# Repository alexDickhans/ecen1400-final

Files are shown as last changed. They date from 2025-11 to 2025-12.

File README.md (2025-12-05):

# ECEN 1400 Final Project: Interactive Multi-Game Board System

A physical implementation of multiple board games (Gomoku and Connect 4) using Arduino microcontrollers and servo motors, featuring dual input controllers with haptic feedback and game mode selection.

## 📄 [Project Final Report](/final-report.pdf)

## 🎮 Project Overview

This project creates an interactive 5x5 game board system that supports multiple game modes. Players use physical controllers to place X and O pieces represented by servo motor positions. The system includes haptic feedback, game mode selection, and supports two different input methods (button-based and joystick-based controllers).

## 🏗️ System Architecture

The system consists of three main components:

### 1. Main Board Controller (`main-board/`)
- **Hardware**: Arduino Uno with 2x PCA9685 PWM Servo Driver boards
- **Function**: Controls 25 servo motors arranged in a 5x5 grid
- **Features**: 
  - Multiple game modes (Gomoku 3-5 in a row, Connect 4 3-5 in a row)
  - Game mode selection with visual feedback
  - Game logic and win detection
  - Cursor animation and visual feedback
  - Dual controller communication (separate X and O player controllers)
  - Win sequence animations
  - On-board button controls (SELECT and RESET/START)
  - Movement queue system for optimized servo control

### 2. Coarse Input Controller (`coarse/`)
- **Hardware**: Arduino Uno with 5 digital buttons
- **Function**: Provides directional input via discrete buttons (typically used as one player controller)
- **Features**:
  - Up/Down/Left/Right/Select button inputs
  - Dual UART communication (Hardware Serial + SoftwareSerial)
  - Haptic feedback motor control with multiple patterns

### 3. Fine Input Controller (`fine/`)
- **Hardware**: Arduino Uno with analog joystick
- **Function**: Provides directional input via joystick (typically used as the other player controller)
- **Features**:
  - Analog joystick with threshold detection
  - Dual UART communication (Hardware Serial + SoftwareSerial)
  - Haptic feedback motor control with multiple patterns

## 🔌 Pin Configurations

### Main Board Controller
- **PCA9685 Board 1** (Address 0x40, A0 bridged): Controls servos 0-14
- **PCA9685 Board 2** (Address 0x60, all address pins grounded): Controls servos 15-24
- **X Player Controller**: AltSoftSerial on pins 8/9 (RX/TX)
- **O Player Controller**: SoftwareSerial on pins 5/6 (RX/TX)
- **SELECT Button**: Pin 7 (INPUT_PULLUP)
- **RESET/START Button**: Pin 8 (INPUT_PULLUP) - Note: conflicts with AltSoftSerial, consider different pin

### Coarse Controller
- **Buttons**: 
  - Up: Pin 8
  - Down: Pin 9
  - Left: Pin 10
  - Right: Pin 11
  - Select: Pin 12
- **Haptic Motor**: Pin 13
- **UART**: Hardware Serial (0/1) + SoftwareSerial (4/5 - RX/TX)

### Fine Controller
- **Joystick X**: Pin A0
- **Joystick Y**: Pin A1
- **Select Button**: Pin 3 (INPUT_PULLUP)
- **Haptic Motor**: Pin 13
- **UART**: Hardware Serial (0/1) + SoftwareSerial (6/7 - RX/TX)

## 🎯 Game Features

### Game Modes
The system supports 6 different game modes:

**Gomoku Modes (0-2):**
- Mode 0: 3 in a row (tic-tac-toe style, uses 3x3 sub-board)
- Mode 1: 4 in a row
- Mode 2: 5 in a row (classic Gomoku)

**Connect 4 Modes (3-5):**
- Mode 3: Connect 3
- Mode 4: Connect 4 (classic)
- Mode 5: Connect 5

### Servo States
- **STATE_NONE** (Position 300): Empty space
- **STATE_X** (Position 470): Player X piece
- **STATE_O** (Position 100): Player O piece

### Game Mechanics
- **5x5 Grid**: 25 positions for game pieces
- **Variable Win Condition**: 3-5 pieces in a row depending on selected mode
- **Turn-based**: Players alternate turns (X goes first)
- **Visual Cursor**: Animated cursor shows current selection
  - Gomoku: Full 2D movement (up/down/left/right)
  - Connect 4: Horizontal movement only (left/right) in top row, pieces drop to lowest available position
- **Haptic Feedback**: Controllers vibrate on valid/invalid moves and turn changes
- **Game Mode Selection**: Visual pattern on board shows selected mode before game starts

### Animations
- **Cursor Wiggle**: Visual indication of current position (different patterns for empty vs occupied positions)
- **Checkerboard Pattern**: Idle state animation (alternates every 7 seconds)
- **Game Mode Display**: Visual pattern showing selected game mode (diagonal for Gomoku, bottom row for Connect 4)
- **Connect 4 Drop Animation**: Pieces animate falling from top to target position
- **Win Sequence**: Celebration animation when game is won (expanding wave pattern)

## 📡 Communication Protocol

### Input Commands (Controllers → Main Board)
- `u` - Move cursor up (Gomoku only)
- `d` - Move cursor down (Gomoku only)
- `l` - Move cursor left (or decrease game mode in selection)
- `r` - Move cursor right (or increase game mode in selection)
- `s` - Select/place piece (or start game in selection)
- `x` or `o` - Decrease game mode (in game selection mode)

### Feedback Commands (Main Board → Controllers)
- `y` - Valid move (yes)
- `n` - Invalid move (no)
- `t` - Turn notification (your turn)
- `w` - Game won (win pattern)
- `l` - Game lost (lose pattern)

**Note**: Feedback is sent only to the active player's controller (X or O player receives separate communication)

### Haptic Patterns
- **Yes Pattern** (`y`): Three quick short pulses (...)
- **No Pattern** (`n`): Four long pulses (----)
- **Turn Pattern** (`t`): Long-short-long pulses (-.-)
- **Win Pattern** (`w`): Four dots, two dashes (....--)
- **Lose Pattern** (`l`): Four dashes, two dots (----..)

**Timing**:
- Short pulse: 100ms
- Long pulse: 300ms
- Pause between pulses: 150ms

## 🛠️ Setup Instructions

### Hardware Setup
1. **Main Board**:
   - Connect 2x PCA9685 boards to Arduino Uno via I2C (SDA/SCL)
   - Connect 25 servo motors to PWM outputs
   - First PCA9685: Bridge A0 pin for address 0x40, controls servos 0-14
   - Second PCA9685: Ground all address pins for address 0x60, controls servos 15-24
   - Connect SELECT button to pin 7 (with pull-up)
   - Connect RESET/START button to pin 8 (with pull-up) - Note: may conflict with AltSoftSerial
   - Connect X player controller via AltSoftSerial (pins 8/9)
   - Connect O player controller via SoftwareSerial (pins 5/6)

2. **Controllers**:
   - Connect buttons/joystick as per pin configurations
   - Connect haptic motors to pin 13
   - Connect UART communication lines (both Hardware Serial and SoftwareSerial)

### Software Setup
1. Install required Arduino libraries:
   - `Adafruit PWM Servo Driver Library` (for PCA9685 control)
   - `SoftwareSerial` (built-in, for O player controller)
   - `AltSoftSerial` (for X player controller - more reliable than SoftwareSerial)

2. Upload firmware to each Arduino:
   - `main-board.ino` to main controller
   - `coarse.ino` to button controller (assign to one player)
   - `fine.ino` to joystick controller (assign to other player)

## 🎮 How to Play

1. **Enter Game Selection**: Press SELECT button on main board or 's' on either controller
2. **Select Game Mode**: 
   - Use left/right buttons or l/r commands to cycle through modes (0-5)
   - Board displays visual pattern showing selected mode
   - Gomoku modes (0-2): Diagonal pattern showing pieces in a row
   - Connect 4 modes (3-5): Bottom row pattern showing pieces in a row
3. **Start Game**: Press SELECT button again or 's' command to start
4. **Move Cursor**: 
   - Gomoku: Use up/down/left/right to navigate full board
   - Connect 4: Use left/right to select column (cursor stays in top row)
5. **Place Piece**: Press select to place your piece
   - Connect 4: Piece automatically drops to lowest available position in column
6. **Win**: Get required pieces in a row (3-5 depending on mode) to win
7. **Reset**: Press RESET/START button on main board to return to idle, or game automatically resets after win sequence

## 🔧 Technical Details

### Servo Control
- **Frequency**: 50 Hz PWM
- **Pulse Range**: 90-525 (out of 4096)
- **Actual Positions**: 
  - None: 300 (middle-low)
  - X: 470 (middle-high)
  - O: 100 (low)
- **Movement Queue**: Movements are queued and processed with randomization and staggering to prevent power spikes
- **Concurrent Movements**: Maximum 10 servos can move simultaneously
- **Movement Duration**: 300ms per movement

### Debouncing
- **Button Debounce**: 50ms (main board and controllers)
- **Joystick Debounce**: 100ms
- **Joystick Threshold Values**: 
  - Left: < 400
  - Right: > 600
  - Up: < 400
  - Down: > 600
  - Center: 400-600 (both axes)

### Timing
- **Haptic Pulse**: 100ms duration (short), 300ms (long)
- **Pattern Timing**: 100ms short, 300ms long pulses, 150ms pause between
- **Cursor Animation**: 
  - Empty position: 300ms intervals, ±50 amplitude
  - Occupied position: 150ms intervals, ±25 amplitude
- **Checkerboard Pattern**: Changes every 7 seconds
- **Win Sequence**: 200ms per step, 5 seconds total
- **Connect 4 Drop**: ~200-300ms per row during animation

## 🎯 Game Rules

### Gomoku Modes
- Players alternate turns (X goes first)
- Place pieces on empty positions only
- Win by getting the required pieces in a row (3, 4, or 5 depending on mode)
- Rows can be horizontal, vertical, or diagonal
- Mode 0 (3-in-a-row): Uses 3x3 sub-board (indices 1-3)
- Game ends on win or board full (draw)

### Connect 4 Modes
- Players alternate turns (X goes first)
- Pieces drop to the lowest available position in selected column
- Cannot place in full columns
- Win by getting the required pieces in a row (3, 4, or 5 depending on mode)
- Rows can be horizontal, vertical, or diagonal
- Game ends on win or board full (draw)

## 📁 Project Structure

```
ecen1400-final/
├── README.md              # This file
├── main-board/            # Main game controller
│   └── main-board.ino     # Servo control and game logic
├── coarse/                # Button input controller
│   └── coarse.ino         # Digital button handling
└── fine/                  # Joystick input controller
    └── fine.ino           # Analog joystick handling
```

## 🎓 Educational Value

This project demonstrates:
- **Microcontroller Programming**: Arduino C++ programming with state machines
- **Hardware Integration**: Servo control via I2C, multiple PWM driver boards
- **Game Development**: Multiple game modes, win detection algorithms, turn-based logic
- **User Interface Design**: Haptic feedback, visual feedback, game mode selection
- **Communication Protocols**: Dual UART serial communication (Hardware Serial + SoftwareSerial/AltSoftSerial)
- **System Integration**: Multi-device coordination with separate player controllers
- **Resource Management**: Movement queue system, concurrent movement limiting to prevent power issues
- **Animation Systems**: Cursor animations, win sequences, drop animations

## 🔧 Additional Features

### Simulation Mode
The main board code includes a `SIMULATION_MODE` flag (set to 0 by default) that allows testing game logic without servo hardware. When enabled, board state is printed to serial instead of moving servos.

### Debug Commands (Serial Monitor)
- `start` - Enter game selection mode
- `display` - Show current game state
- `reset` - Reset game to idle state

### State Management
- **IDLE**: Shows checkerboard pattern, waiting for game start
- **GAME_SELECT**: Shows selected game mode pattern, allows mode selection
- **ACTIVE**: Game is running, players can make moves

---

**Course**: ECEN 1400 - Introduction to Digital And Analog Electronics  
**Project**: Interactive Multi-Game Board System  
**Technologies**: Arduino, C++, Servo Motors, Haptic Feedback, I2C, UART Communication

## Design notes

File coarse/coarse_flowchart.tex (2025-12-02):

\begin{center}
\begin{tikzpicture}[
    node distance = 0.6cm and 0.6cm,
    auto,
    font=\footnotesize,
    % Styles
    startstop/.style={rectangle, rounded corners, minimum width=2.5cm, minimum height=0.8cm, text centered, draw=black, fill=red!30},
    process/.style={rectangle, minimum width=2.5cm, minimum height=0.8cm, text centered, draw=black, fill=blue!30},
    decision/.style={diamond, minimum width=2cm, minimum height=0.8cm, text centered, draw=black, fill=green!30, inner sep=0pt},
    arrow/.style={thick,->,>=stealth}
]

% Nodes
\node [startstop] (start) {Start};
\node [process, below=of start] (init) {Init Hardware};
\node [startstop, below=of init] (loop) {Main Loop};

\node [process, below=of loop] (check_uart) {Check UART};
\node [decision, below=of check_uart] (has_cmd) {Command?};
\node [process, right=of has_cmd, xshift=0.5cm] (play) {Play Pattern};

\node [process, below=of has_cmd, yshift=-0.5cm] (check_btn) {Process Buttons};
\node [decision, below=of check_btn] (is_pressed) {Pressed?};
\node [process, right=of is_pressed, xshift=0.5cm] (send) {Send Command};

\node [process, below=of is_pressed, yshift=-0.5cm] (haptic) {Handle Haptic};
\node [process, below=of haptic] (delay) {Delay 10ms};

% Arrows
\draw [arrow] (start) -- (init);
\draw [arrow] (init) -- (loop);
\draw [arrow] (loop) -- (check_uart);
\draw [arrow] (check_uart) -- (has_cmd);

% Command branch
\draw [arrow] (has_cmd) -- node[anchor=south] {Yes} (play);
\draw [arrow] (play) |- (check_btn);
\draw [arrow] (has_cmd) -- node[anchor=east] {No} (check_btn);

% Button branch
\draw [arrow] (check_btn) -- (is_pressed);
\draw [arrow] (is_pressed) -- node[anchor=south] {Yes} (send);
\draw [arrow] (send) |- (haptic);
\draw [arrow] (is_pressed) -- node[anchor=east] {No} (haptic);

% Loop back
\draw [arrow] (haptic) -- (delay);
\draw [arrow] (delay) -- ++(0,-0.8) -| ($(loop.west) + (-1cm,0)$) -- (loop.west);

\end{tikzpicture}
\end{center}

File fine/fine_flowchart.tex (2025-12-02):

\begin{center}
\begin{tikzpicture}[
    node distance = 0.6cm and 0.6cm,
    auto,
    font=\footnotesize,
    % Styles
    startstop/.style={rectangle, rounded corners, minimum width=2.5cm, minimum height=0.8cm, text centered, draw=black, fill=red!30},
    process/.style={rectangle, minimum width=2.5cm, minimum height=0.8cm, text centered, draw=black, fill=blue!30},
    decision/.style={diamond, minimum width=2cm, minimum height=0.8cm, text centered, draw=black, fill=green!30, inner sep=0pt},
    arrow/.style={thick,->,>=stealth}
]

% Nodes
\node [startstop] (start) {Start};
\node [process, below=of start] (init) {Init Hardware};
\node [startstop, below=of init] (loop) {Main Loop};

\node [process, below=of loop] (check_uart) {Check UART};
\node [decision, below=of check_uart] (has_cmd) {Command?};
\node [process, right=of has_cmd, xshift=0.5cm] (play) {Play Pattern};

\node [process, below=of has_cmd, yshift=-0.5cm] (check_joy) {Process Joystick};
\node [decision, below=of check_joy] (has_dir) {Direction?};
\node [process, right=of has_dir, xshift=0.5cm] (send) {Send Command};

\node [process, below=of has_dir, yshift=-0.5cm] (haptic) {Handle Haptic};
\node [process, below=of haptic] (delay) {Delay 10ms};

% Arrows
\draw [arrow] (start) -- (init);
\draw [arrow] (init) -- (loop);
\draw [arrow] (loop) -- (check_uart);
\draw [arrow] (check_uart) -- (has_cmd);

% Command branch
\draw [arrow] (has_cmd) -- node[anchor=south] {Yes} (play);
\draw [arrow] (play) |- (check_joy);
\draw [arrow] (has_cmd) -- node[anchor=east] {No} (check_joy);

% Joystick branch
\draw [arrow] (check_joy) -- (has_dir);
\draw [arrow] (has_dir) -- node[anchor=south] {Yes} (send);
\draw [arrow] (send) |- (haptic);
\draw [arrow] (has_dir) -- node[anchor=east] {No} (haptic);

% Loop back
\draw [arrow] (haptic) -- (delay);
\draw [arrow] (delay) -- ++(0,-0.8) -| ($(loop.west) + (-1cm,0)$) -- (loop.west);

\end{tikzpicture}
\end{center}

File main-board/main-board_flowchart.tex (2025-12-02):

\begin{center}
\begin{tikzpicture}[
    node distance = 0.35cm and 0.8cm,
    auto,
    font=\scriptsize,
    % Styles
    startstop/.style={rectangle, rounded corners, minimum width=2cm, minimum height=0.5cm, text centered, draw=black, fill=red!30},
    process/.style={rectangle, minimum width=2cm, minimum height=0.5cm, text centered, draw=black, fill=blue!30},
    decision/.style={diamond, minimum width=1.5cm, minimum height=0.5cm, text centered, draw=black, fill=green!30, inner sep=0pt},
    arrow/.style={thick,->,>=stealth}
]

% Nodes
\node [startstop] (start) {Start};
\node [process, below=of start] (init) {Init};
\node [startstop, below=of init] (loop) {Loop};
\node [process, below=of loop] (queue) {Process Queue};
\node [decision, below=of queue] (state) {State?};

% Side states
\node [process, left=of state, xshift=-2.5cm] (idle) {IDLE};
\node [process, right=of state, xshift=3.5cm] (select) {SELECT};

% Active state flow
\node [decision, below=of state, yshift=-0.2cm] (win) {Win Seq?};
\node [process, right=of win, xshift=1.0cm] (update) {Update Win};

\node [process, below=of win, yshift=-0.2cm] (check) {Check Wins};
\node [process, below=of check] (input) {Proc Input};
\node [decision, below=of input] (valid) {Valid?};

\node [process, below=of valid, yshift=-0.2cm] (move) {Make Move};
\node [process, below=of move] (check2) {Check Win};
\node [decision, below=of check2] (over) {Game Over?};

\node [process, right=of over, xshift=2.5cm] (switch) {Switch};
\node [process, left=of over, xshift=-1.0cm] (cont) {Continue};

\node [process, below=of over, yshift=-0.5cm] (delay) {Delay};

% Arrows
\draw [arrow] (start) -- (init);
\draw [arrow] (init) -- (loop);
\draw [arrow] (loop) -- (queue);
\draw [arrow] (queue) -- (state);

% State branches
\draw [arrow] (state) -- node[above] {IDLE} (idle);
\draw [arrow] (state) -- node[above] {SELECT} (select);
\draw [arrow] (state) -- node[right] {ACTIVE} (win);

% Active flow
\draw [arrow] (win) -- node[above] {Yes} (update);
\draw [arrow] (win) -- node[right] {No} (check);

\draw [arrow] (check) -- (input);
\draw [arrow] (input) -- (valid);

\draw [arrow] (valid) -- node[right] {Yes} (move);
% Valid No -> Delay (route left, wide)
\draw [arrow] (valid) -| ($(valid.west) + (-1.5cm,0)$) |- ($(delay.west) + (0,0.2cm)$);

\draw [arrow] (move) -- (check2);
\draw [arrow] (check2) -- (over);

\draw [arrow] (over) -- node[above] {No} (switch);
\draw [arrow] (over) -- node[above] {Yes} (cont);

% Merging to Delay
\draw [arrow] (idle) |- ($(delay.west) + (-0.5cm,0)$);
\draw [arrow] (select) |- ($(delay.east) + (0.5cm,0)$);

% Update Win -> Delay
\draw [arrow] (update) |- ($(delay.east) + (0.2cm,0.2cm)$);

% Switch -> Delay
\draw [arrow] (switch) |- (delay);

% Continue -> Delay
\draw [arrow] (cont) |- (delay);

% Loop back
\draw [arrow] (delay) -- ++(0,-0.5) -| ($(loop.west) + (-5.5cm,0)$) -- (loop.west);

\end{tikzpicture}
\end{center}

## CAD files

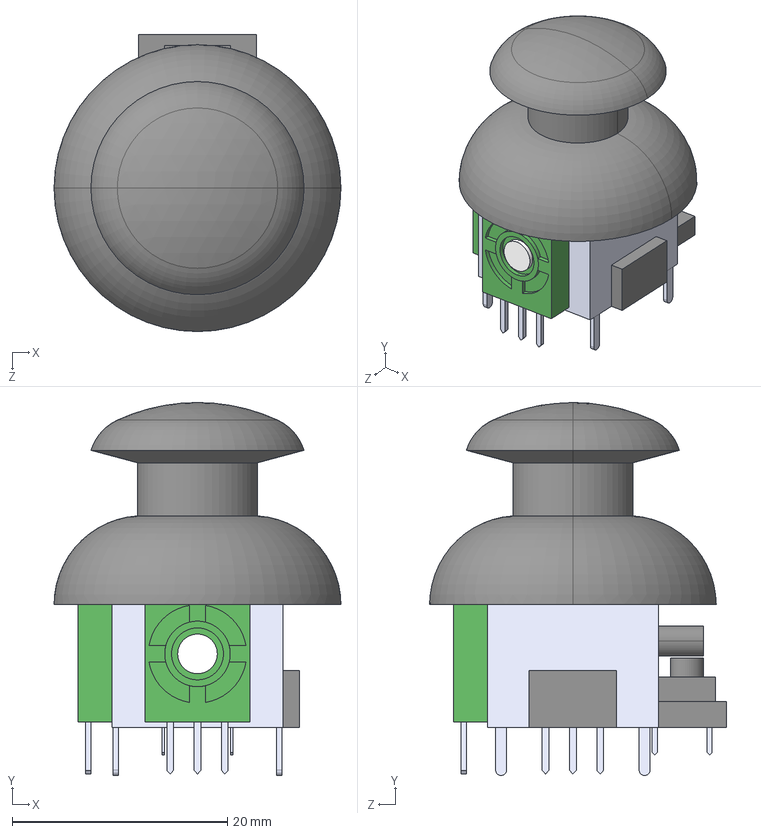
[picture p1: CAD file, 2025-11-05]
final_schematics/COM_09032/COM-09032.step
26.7 x 34.7 x 27.6 mm

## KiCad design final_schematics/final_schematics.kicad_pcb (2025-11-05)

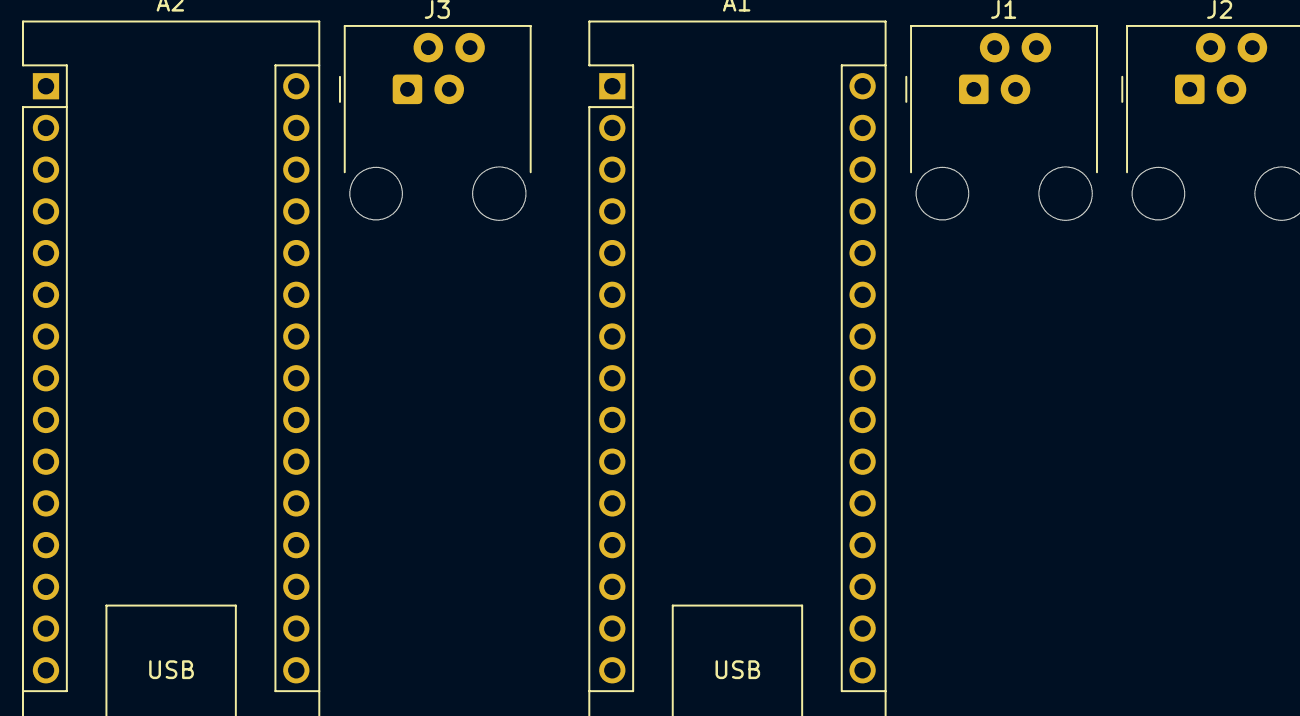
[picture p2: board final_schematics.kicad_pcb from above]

Board: 2 copper layers, 5 parts (0 on the bottom side), 6 nets, no tracks yet.

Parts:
A1, A2: Arduino_Nano_v3.x; Arduino_Nano
J1, J2: Input device 1; RJ9_Evercom_5301-440xxx_Horizontal
J3: RJ9; RJ9_Evercom_5301-440xxx_Horizontal

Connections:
+5V: A2.30 (VIN), J1.4, J2.4, J3.4
/Coarse Motor Control/RX: A1.8 (D5), A2.8 (D5), J1.2, J3.2
/Coarse Motor Control/TX: A1.7 (D4), A2.7 (D4), J1.3, J3.3
/Main Board/RX2: A1.9 (D6), J2.3
/Main Board/TX2: A1.10 (D7), J2.2
GND: A2.4 (GND), A2.29 (GND), J1.1, J2.1, J3.1

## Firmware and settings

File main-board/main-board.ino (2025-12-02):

/*
 * 5x5 Servo Grid Controller using 2 PCA9685 Boards
 * 
 * Board Configuration:
 * - First PCA9685: Address 0x40, physical channels 6-15, controls grid servo indices 0-9 (first 10 squares)
 * - Second PCA9685: Address 0x60, physical channels 1-15, controls grid servo indices 10-24 (next 15 squares)
 * 
 * Grid Layout (5x5):
 * Servo positions in grid:
 *  0  1  2  3  4
 *  5  6  7  8  9
 * 10 11 12 13 14
 * 15 16 17 18 19
 * 20 21 22 23 24
 * 
 * Servo Connection Ordering:
 * - First PCA9685 (0x40):
 *   Physical channels 6-15 connect to grid servo indices 0-9
 *   Grid mapping: Servo index = row * 5 + col
 *   Physical channel = servoIndex + 6 (e.g., servoIndex 0 -> channel 6, servoIndex 9 -> channel 15)
 *   
 * - Second PCA9685 (0x60):
 *   Physical channels 1-15 connect to grid servo indices 10-24
 *   Physical channel = servoIndex - 9 (e.g., servoIndex 10 -> channel 1, servoIndex 24 -> channel 15)
 */

#include <Wire.h>
#include <Adafruit_PWMServoDriver.h>
#include <SoftwareSerial.h>
#include <AltSoftSerial.h>

// Create PCA9685 objects
Adafruit_PWMServoDriver pwm1 = Adafruit_PWMServoDriver(0x40); // First board (A0 bridged)
Adafruit_PWMServoDriver pwm2 = Adafruit_PWMServoDriver(0x60); // Second board (all grounded)

// AltSoftSerial for communication with X player controller (more reliable)
AltSoftSerial playerXSerial; // Uses pins 8/9 (RX green/TX yellow)
// SoftwareSerial for communication with O player controller
SoftwareSerial playerOSerial(5, 6); // RX green, TX yellow for O player controller

// Button pins
#define SELECT_BUTTON_PIN 7
#define RESET_START_BUTTON_PIN 8

// Servo configuration
#define SERVO_FREQ 50 // Analog servos run at ~50 Hz updates
#define SERVO_MIN 90 // Minimum pulse length count (out of 4096)
#define SERVO_MAX 525 // Maximum pulse length count (out of 4096)

// Grid dimensions
#define GRID_SIZE 5
#define TOTAL_SERVOS 25

// Win condition - number of pieces in a row needed to win (will be set based on gamemode)
uint8_t winCondition = 4;

// Maximum number of servos that can move simultaneously (adjustable)
#define MAX_CONCURRENT_SERVO_MOVEMENTS 10

// Movement tracking duration (milliseconds a servo is considered "moving")
#define MOVEMENT_DURATION 300

// Simulation mode - set to 1 to enable simulation (no servo movement, prints board state)
#define SIMULATION_MODE 0

// Servo states (3 distinct positions for Gomoku)
enum ServoState {
  STATE_NONE = 0,   // No piece (low position)
  STATE_X = 1,      // X piece (middle position)  
  STATE_O = 2       // O piece (high position)
};

// Game mode states
enum GameModeState {
  STATE_IDLE = 0,
  STATE_GAME_SELECT = 1,
  STATE_ACTIVE = 2
};

// Game mode types
enum GameType {
  GAME_GOMOKU = 0,
  GAME_CONNECT4 = 1
};

// Grid state array - tracks current state of each servo
ServoState gridState[TOTAL_SERVOS];

// Game state variables
GameModeState gameModeState = STATE_IDLE;
uint8_t currentGameMode = 0; // 0-2: Gomoku 3-5, 3-5: Connect4 3-5
int cursorRow = 0;
int cursorCol = 0;
ServoState currentPlayer = STATE_X; // X starts first
bool gameActive = false; // Start inactive
bool gameStarted = false;
unsigned long lastWiggleTime = 0;
bool isWiggling = false;
int wiggleStep = 0;

// Checkerboard animation variables
unsigned long lastPatternTime = 0;
bool checkerboardState = false; // false = X pattern, true = O pattern

// Gamemode display variables
uint8_t lastDisplayedGameMode = 255; // Track last displayed gamemode (255 = not set)
unsigned long lastGameModeChangeTime = 0; // Track when gamemode was last changed for timeout
const unsigned long GAME_SELECT_TIMEOUT = 15000; // 15 seconds timeout

// Win sequence variables
bool winSequenceActive = false;
unsigned long winSequenceStartTime = 0;
int winSequenceStep = 0;
int lastMoveRow = 0;
int lastMoveCol = 0;
ServoState winningPlayer = STATE_NONE;

// Button state variables
bool selectButtonPressed = false;
bool resetStartButtonPressed = false;
bool lastSelectButtonState = HIGH;
bool lastResetStartButtonState = HIGH;
unsigned long lastSelectDebounceTime = 0;
unsigned long lastResetStartDebounceTime = 0;
const unsigned long DEBOUNCE_DELAY = 50; // 50ms debounce delay

// Movement tracking structures (optimized for memory)
struct Movement {
  uint8_t servoIndex;      // 0-24, so uint8_t is sufficient
  uint16_t position;       // Pulse width (0-4095), uint16_t is sufficient
  unsigned long startTime;
  bool active;
};

// Flag to use immediate movements (no delays) for gamemode display
bool useImmediateMovements = false;

Movement activeMovements[MAX_CONCURRENT_SERVO_MOVEMENTS];
struct PendingMovement {
  uint8_t servoIndex;
  uint16_t position;
  unsigned long scheduledStartTime;  // When this movement should actually start
};

// Reduced queue size to save memory (15 items = ~45 bytes instead of ~400 bytes)
#define MOVEMENT_QUEUE_SIZE 25
PendingMovement movementQueue[MOVEMENT_QUEUE_SIZE];
uint8_t queueHead = 0;
uint8_t queueTail = 0;
uint8_t queueSize = 0;
unsigned long lastMovementStartTime = 0;  // Track when last movement started for staggering

// Servo position mapping for each state
const int servoPositions[3] = {
  300,  // STATE_NONE
  470,                    // STATE_X
  100                    // STATE_O
};

void setup() {
  Serial.begin(115200);
  Serial.println(F("Gomoku Game Starting..."));
  
  // Initialize AltSoftSerial for X player controller
  playerXSerial.begin(9600);
  // Initialize SoftwareSerial for O player controller
  playerOSerial.begin(9600);
  
  // Initialize button pins
  pinMode(SELECT_BUTTON_PIN, INPUT_PULLUP);
  pinMode(RESET_START_BUTTON_PIN, INPUT_PULLUP);
  
  // Initialize PCA9685 boards (only if not in simulation mode)
  #if SIMULATION_MODE
    Serial.println(F("SIMULATION MODE ENABLED - Servos will not move, board state will be printed to serial"));
  #else
    pwm1.begin();
    pwm1.setOscillatorFrequency(27000000);
    pwm1.setPWMFreq(SERVO_FREQ);
    
    pwm2.begin();
    pwm2.setOscillatorFrequency(27000000);
    pwm2.setPWMFreq(SERVO_FREQ);
  #endif
  
  // Initialize movement tracking
  for (int i = 0; i < MAX_CONCURRENT_SERVO_MOVEMENTS; i++) {
    activeMovements[i].active = false;
  }
  queueHead = 0;
  queueTail = 0;
  queueSize = 0;
  
  // Seed random number generator for random queue processing
  randomSeed(analogRead(0));
  
  // Initialize game board
  initializeGame();
  
  Serial.println(F("Gomoku game initialized!"));
  #if SIMULATION_MODE
    Serial.println(F("SIMULATION MODE: Board state will be printed instead of moving servos"));
  #else
    Serial.println(F("Press SELECT to choose gamemode, then SELECT again to start"));
  #endif
  Serial.println(F("Controls:"));
  Serial.println(F("  - X/O controllers: l/r to change gamemode, s to enter/start"));
  Serial.println(F("  - SELECT button: Enter gamemode select or start game"));
}

void loop() {
  // Process movement queue to allow queued movements to start when slots become available
  processMovementQueue();
  
  if (gameModeState == STATE_IDLE) {
    // Show checkerboard pattern when idle
    updateCheckerboardPattern();
    
    // Check for controller and button input
    checkControllerInput();
    checkButtonInput();
    
    // Check for serial commands (for debugging)
    if (Serial.available()) {
      String command = Serial.readStringUntil('\n');
      command.trim();
      
      if (command == "start") {
        enterGameSelect();
      } else if (command == "display") {
        displayGameState();
      }
    }
    
    delay(50);
    return;
  }
  
  if (gameModeState == STATE_GAME_SELECT) {
    // Check for timeout - if same gamemode for more than 15 seconds, return to idle
    if (millis() - lastGameModeChangeTime >= GAME_SELECT_TIMEOUT) {
      returnToIdle();
      return;
    }
    
    // Show gamemode pattern on board (similar to checkerboard pattern)
    updateGamemodeDisplay();
    
    // Check for controller and button input
    checkControllerInput();
    checkButtonInput();
    
    delay(50);
    return;
  }
  
  // STATE_ACTIVE - game is running
  if (!gameActive) {
    delay(50);
    return;
  }
  
  // Handle win sequence if active
  if (winSequenceActive) {
    updateWinSequence();
    processMovementQueue(); // Also process queue during win sequence
    delay(100);
    return;
  }
  
  // Check for wins at the start of each turn (in case a win was missed)
  checkForWins();
  
  // Handle cursor wiggle animation
  updateCursorWiggle();
  
  // Check for input from player controllers
  checkControllerInput();
  
  // Check for button input
  checkButtonInput();
  
  // Check for serial commands (for debugging)
  if (Serial.available()) {
    String command = Serial.readStringUntil('\n');
    command.trim();
    
    if (command == "display") {
      displayGameState();
    } else if (command == "reset") {
      resetGame();
    }
  }
  
  delay(50);
}

/**
 * Initialize game board and servos
 */
void initializeGame() {
  // Initialize all servos to NONE position
  for (int i = 0; i < TOTAL_SERVOS; i++) {
    gridState[i] = STATE_NONE;
    setServoPosition(i, servoPositions[STATE_NONE]);
  }
  
  // Reset game state
  gameModeState = STATE_IDLE;
  currentGameMode = 0;
  cursorRow = 0;
  cursorCol = 0;
  currentPlayer = STATE_X;
  gameActive = false; // Start inactive
  gameStarted = false;
  winSequenceActive = false;
  isWiggling = false;
  checkerboardState = false;
  lastPatternTime = millis();
  winningPlayer = STATE_NONE;
  winCondition = 4;
  
  delay(1000); // Allow servos to reach position
  
  // Start with checkerboard pattern
  updateCheckerboardPattern();
}

/**
 * Enter game select mode
 */
void enterGameSelect() {
  gameModeState = STATE_GAME_SELECT;
  currentGameMode = 0; // Start at first gamemode
  gameStarted = false; // Reset game started flag
  lastDisplayedGameMode = 255; // Force update on next loop
  lastGameModeChangeTime = millis(); // Initialize timeout timer
}

/**
 * Update gamemode display on board
 * Shows pattern of squares in a row based on gamemode
 * Similar approach to checkerboard pattern - continuously applies the pattern
 */
void updateGamemodeDisplay() {
  // Only update if gamemode changed
  if (lastDisplayedGameMode == currentGameMode) {
    return; // Already displaying correct pattern
  }
  
  lastDisplayedGameMode = currentGameMode;
  
  uint8_t squaresInRow;
  bool isConnect4 = (currentGameMode >= 3);
  
  if (isConnect4) {
    // Connect 4 modes (3-5): map to 3-5 in a row
    squaresInRow = currentGameMode - 3 + 3; // 3, 4, or 5
  } else {
    // Gomoku modes (0-2): 3-5 in a row
    squaresInRow = currentGameMode + 3; // 3, 4, or 5
  }
  
  // Apply pattern to all servos (similar to checkerboard pattern)
  for (int row = 0; row < GRID_SIZE; row++) {
    for (int col = 0; col < GRID_SIZE; col++) {
      int servoIndex = row * GRID_SIZE + col;
      ServoState targetState = STATE_NONE;
      
      if (isConnect4) {
        // Connect 4: show pattern on bottom row
        uint8_t startCol = (GRID_SIZE - squaresInRow) / 2;
        if (row == GRID_SIZE - 1 && col >= startCol && col < startCol + squaresInRow) {
          targetState = STATE_X;
        }
      } else {
        // Gomoku: show pattern on diagonal
        uint8_t startRow = 0;
        uint8_t startCol = 0;
        if (squaresInRow == 3) {
          startRow = 1;
          startCol = 1;
        }
        
        if (row >= startRow && row < startRow + squaresInRow && 
            col >= startCol && col < startCol + squaresInRow && 
            row == col) {
          targetState = STATE_X;
        }
      }
      
      // Update if state changed
      if (gridState[servoIndex] != targetState) {
        gridState[servoIndex] = targetState;
        setServoPosition(servoIndex, servoPositions[targetState]);
      }
    }
  }
}

/**
 * Refresh gamemode display to maintain consistency
 * Only updates servos that are not in the correct position
 */
void refreshGamemodeDisplay() {
  uint8_t squaresInRow = currentGameMode + 3;
  bool isConnect4 = (currentGameMode >= 3);
  
  // Use immediate movements for refresh
  useImmediateMovements = true;
  
  if (isConnect4) {
    // Connect 4: show pattern on bottom row
    uint8_t startCol = (GRID_SIZE - squaresInRow) / 2;
    for (uint8_t i = 0; i < squaresInRow; i++) {
      int col = startCol + i;
      if (col < GRID_SIZE) {
        int servoIndex = (GRID_SIZE - 1) * GRID_SIZE + col;
        // Only update if state doesn't match
        if (gridState[servoIndex] != STATE_X) {
          gridState[servoIndex] = STATE_X;
          setServoPosition(servoIndex, servoPositions[STATE_X]);
        }
      }
    }
    // Clear other positions
    for (int i = 0; i < TOTAL_SERVOS; i++) {
      int row = i / GRID_SIZE;
      int col = i % GRID_SIZE;
      bool shouldBeX = (row == GRID_SIZE - 1 && col >= (GRID_SIZE - squaresInRow) / 2 && 
                        col < (GRID_SIZE - squaresInRow) / 2 + squaresInRow);
      if (!shouldBeX && gridState[i] != STATE_NONE) {
        gridState[i] = STATE_NONE;
        setServoPosition(i, servoPositions[STATE_NONE]);
      }
    }
  } else {
    // Gomoku: show pattern on diagonal
    uint8_t startRow = 0;
    uint8_t startCol = 0;
    if (squaresInRow == 3) {
      startRow = 1;
      startCol = 1;
    }
    
    // Update pattern positions
    for (uint8_t i = 0; i < squaresInRow; i++) {
      int row = startRow + i;
      int col = startCol + i;
      if (row < GRID_SIZE && col < GRID_SIZE) {
        int servoIndex = row * GRID_SIZE + col;
        if (gridState[servoIndex] != STATE_X) {
          gridState[servoIndex] = STATE_X;
          setServoPosition(servoIndex, servoPositions[STATE_X]);
        }
      }
    }
    // Clear other positions
    for (int i = 0; i < TOTAL_SERVOS; i++) {
      int row = i / GRID_SIZE;
      int col = i % GRID_SIZE;
      bool shouldBeX = false;
      if (squaresInRow == 3) {
        shouldBeX = (row >= 1 && row < 4 && col >= 1 && col < 4 && row == col);
      } else {
        shouldBeX = (row == col && row < squaresInRow);
      }
      if (!shouldBeX && gridState[i] != STATE_NONE) {
        gridState[i] = STATE_NONE;
        setServoPosition(i, servoPositions[STATE_NONE]);
      }
    }
  }
  
  useImmediateMovements = false;
  processMovementQueue();
}

/**
 * Set a specific servo in the grid to a given state
 * @param row - Row index (0-4)
 * @param col - Column index (0-4)
 * @param state - Servo state (STATE_NONE, STATE_X, STATE_O)
 */
void setGridState(int row, int col, ServoState state) {
  if (row < 0 || row >= GRID_SIZE || col < 0 || col >= GRID_SIZE) {
    Serial.println(F("Error: Grid coordinates out of range"));
    return;
  }
  
  int servoIndex = row * GRID_SIZE + col;
  gridState[servoIndex] = state;
  setServoPosition(servoIndex, servoPositions[state]);
}

/**
 * Set all servos to the same state
 * @param state - Servo state for all servos
 */
void setAllServos(ServoState state) {
  for (int i = 0; i < TOTAL_SERVOS; i++) {
    gridState[i] = state;
    setServoPosition(i, servoPositions[state]);
  }
}

/**
 * Count number of currently active movements
 */
int countActiveMovements() {
  int count = 0;
  unsigned long currentTime = millis();
  
  for (int i = 0; i < MAX_CONCURRENT_SERVO_MOVEMENTS; i++) {
    if (activeMovements[i].active) {
      // Check if movement has expired
      if (currentTime - activeMovements[i].startTime >= MOVEMENT_DURATION) {
        activeMovements[i].active = false;
      } else {
        count++;
      }
    }
  }
  
  return count;
}

/**
 * Find an available slot for a new movement
 */
int findAvailableMovementSlot() {
  unsigned long currentTime = millis();
  
  // First, clean up expired movements
  for (int i = 0; i < MAX_CONCURRENT_SERVO_MOVEMENTS; i++) {
    if (activeMovements[i].active) {
      if (currentTime - activeMovements[i].startTime >= MOVEMENT_DURATION) {
        activeMovements[i].active = false;
      }
    }
  }
  
  // Find an empty slot
  for (int i = 0; i < MAX_CONCURRENT_SERVO_MOVEMENTS; i++) {
    if (!activeMovements[i].active) {
      return i;
    }
  }
  
  return -1; // No available slot
}

/**
 * Add a movement to the active movements list
 */
void addActiveMovement(uint8_t servoIndex, uint16_t position) {
  int slot = findAvailableMovementSlot();
  if (slot >= 0) {
    activeMovements[slot].servoIndex = servoIndex;
    activeMovements[slot].position = position;
    activeMovements[slot].startTime = millis();
    activeMovements[slot].active = true;
  }
}

/**
 * Add a movement to the queue with staggered start time
 * Waits until there's space in the queue before adding
 */
void enqueueMovement(uint8_t servoIndex, uint16_t position) {
  // Wait until there's space in the queue by processing it
  int maxWaitIterations = 100; // Prevent infinite loops
  int iterations = 0;
  
  while (queueSize >= MOVEMENT_QUEUE_SIZE && iterations < maxWaitIterations) {
    // Process the queue to free up space
    processMovementQueue();
    iterations++;
    
    // Small delay to allow movements to start and free up slots
    if (queueSize >= MOVEMENT_QUEUE_SIZE) {
      delay(1);
    }
  }
  
  // If we still don't have space after waiting, something is wrong
  // but we'll try to add anyway to prevent complete failure
  if (queueSize < MOVEMENT_QUEUE_SIZE) {
    movementQueue[queueTail].servoIndex = servoIndex;
    movementQueue[queueTail].position = position;
    
    unsigned long currentTime = millis();
    unsigned long staggerDelay;
    
    if (useImmediateMovements) {
      // For gamemode display, use very short delays (0-5ms) for immediate feedback
      staggerDelay = random(0, 6);
    } else {
      // Normal game play: use random delay (10-100ms)
      staggerDelay = random(10, 101);
    }
    
    // If this is the first movement or we're starting fresh, use current time
    // Otherwise, accumulate delay from the last scheduled time
    if (queueSize == 0 && lastMovementStartTime == 0) {
      // First movement - schedule immediately with small delay
      movementQueue[queueTail].scheduledStartTime = currentTime + staggerDelay;
    } else {
      // Accumulate delay from the last scheduled time in the queue
      // Find the latest scheduled time in the queue
      unsigned long latestScheduledTime = currentTime;
      for (uint8_t i = 0; i < queueSize; i++) {
        uint8_t queuePos = (queueHead + i) % MOVEMENT_QUEUE_SIZE;
        if (movementQueue[queuePos].scheduledStartTime > latestScheduledTime) {
          latestScheduledTime = movementQueue[queuePos].scheduledStartTime;
        }
      }
      // Schedule after the latest scheduled time plus stagger delay
      movementQueue[queueTail].scheduledStartTime = latestScheduledTime + staggerDelay;
    }
    
    queueTail = (queueTail + 1) % MOVEMENT_QUEUE_SIZE;
    queueSize++;
  }
}

/**
 * Clear the movement queue completely
 */
void clearMovementQueue() {
  queueHead = 0;
  queueTail = 0;
  queueSize = 0;
  lastMovementStartTime = 0;
  
  // Clear all active movements
  for (int i = 0; i < MAX_CONCURRENT_SERVO_MOVEMENTS; i++) {
    activeMovements[i].active = false;
  }
}

/**
 * Process queued movements when slots become available (in random order, with staggered timing)
 */
void processMovementQueue() {
  unsigned long currentTime = millis();
  int attempts = 0;  // Prevent infinite loop
  const int maxAttempts = queueSize;  // Try at most once per queued item
  
  while (queueSize > 0 && attempts < maxAttempts) {
    attempts++;
    
    int slot = findAvailableMovementSlot();
    if (slot < 0) {
      break; // No available slots
    }
    
    // Collect all ready movements first (scheduled time has passed)
    uint8_t readyIndices[MOVEMENT_QUEUE_SIZE];
    uint8_t readyCount = 0;
    
    for (uint8_t i = 0; i < queueSize; i++) {
      uint8_t queuePos = (queueHead + i) % MOVEMENT_QUEUE_SIZE;
      if (movementQueue[queuePos].scheduledStartTime <= currentTime) {
        readyIndices[readyCount] = i;
        readyCount++;
      }
    }
    
    // If no ready movement found, exit (will try again next loop iteration)
    if (readyCount == 0) {
      break;
    }
    
    // Randomly select one from all ready movements
    uint8_t selectedIndex = readyIndices[random(0, readyCount)];
    uint8_t selectedPos = (queueHead + selectedIndex) % MOVEMENT_QUEUE_SIZE;
    
    // Swap the randomly selected ready movement with the head item
    PendingMovement movement = movementQueue[selectedPos];
    movementQueue[selectedPos] = movementQueue[queueHead];
    movementQueue[queueHead] = movement;
    
    // Remove from queue
    queueHead = (queueHead + 1) % MOVEMENT_QUEUE_SIZE;
    queueSize--;
    
    // Update last movement start time for next stagger calculation
    lastMovementStartTime = currentTime;
    
    // Execute the movement
    // Convert logical grid index to physical servo index (vertically mirrored)
    uint8_t physicalIndex = getPhysicalServoIndex(movement.servoIndex);
    
    // First PCA9685 (0x40): handles physical servo indices 0-9 -> physical channels 6-15
    // Second PCA9685 (0x60): handles physical servo indices 10-24 -> physical channels 1-15
    if (physicalIndex >= 0 && physicalIndex <= 9) {
      // First board: physical indices 0-9 map to channels 6-15
      // Physical index 0 -> channel 6, physical index 1 -> channel 7, ..., physical index 9 -> channel 15
      uint8_t channel = physicalIndex + 6;
      pwm1.setPWM(channel, 0, movement.position);
    } else if (physicalIndex >= 10 && physicalIndex <= 24) {
      // Second board: physical indices 10-24 map to channels 1-15
      // Physical index 10 -> channel 1, physical index 11 -> channel 2, ..., physical index 24 -> channel 15
      uint8_t channel = physicalIndex - 9;
      pwm2.setPWM(channel, 0, movement.position);
    }
    
    // Add to active movements
    addActiveMovement(movement.servoIndex, movement.position);
  }
}
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

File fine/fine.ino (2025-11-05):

/*
 * Joystick Input Controller with Dual UART Communication and Haptic Feedback
 * 
 * Features:
 * - Joystick inputs (up/down/left/right/select) using SparkFun joystick
 * - Dual UART communication over hardware Serial pins 0/1 and SoftwareSerial pins 4/5
 * - Haptic feedback control on pin 13
 * - Responds to y/n/t characters for haptic control
 * 
 * UART Commands:
 * - 'y': Yes pattern (...) - three quick short pulses
 * - 'n': No pattern (----) - four long pulses
 * - 't': Test/signal pattern (-.-)
 * 
 * Pin Configuration:
 * - Joystick Horizontal (X): Pin A0
 * - Joystick Vertical (Y): Pin A1
 * - Joystick Select Button: Pin 3 (INPUT_PULLUP)
 * - Haptic Motor: Pin 13
 * - Hardware UART: Pins 0/1 (RX/TX)
 * - Software UART: Pins 4/5 (TX- Yellow/RX - Green)
 * 
 * Joystick Thresholds:
 * - Left: A0 < 400
 * - Right: A0 > 600
 * - Up: A1 < 400
 * - Down: A1 > 600
 * - Center: 400 <= A0 <= 600 AND 400 <= A1 <= 600
 */

#include <SoftwareSerial.h>

// Pin definitions
#define JOYSTICK_X_PIN A0
#define JOYSTICK_Y_PIN A1
#define JOYSTICK_SELECT_PIN 3
#define HAPTIC_PIN 13
#define SOFT_UART_TX_PIN 7
#define SOFT_UART_RX_PIN 6

// Joystick threshold settings
#define JOYSTICK_THRESHOLD_LOW 400
#define JOYSTICK_THRESHOLD_HIGH 600
#define JOYSTICK_CENTER_MIN 400
#define JOYSTICK_CENTER_MAX 600

// Debounce settings
#define DEBOUNCE_DELAY 50
#define JOYSTICK_DEBOUNCE_DELAY 100  // Longer debounce for joystick movement

// Create SoftwareSerial object for additional UART communication
SoftwareSerial softSerial(SOFT_UART_RX_PIN, SOFT_UART_TX_PIN);

// Joystick state tracking
struct JoystickState {
  int xValue;
  int yValue;
  bool selectPressed;
  int lastSelectState;
  unsigned long lastSelectDebounceTime;
  bool selectPressedFlag;
  
  // Direction states
  bool leftPressed;
  bool rightPressed;
  bool upPressed;
  bool downPressed;
  
  // Last direction states for edge detection
  bool lastLeftPressed;
  bool lastRightPressed;
  bool lastUpPressed;
  bool lastDownPressed;
  
  // Direction command sent flags
  bool leftCommandSent;
  bool rightCommandSent;
  bool upCommandSent;
  bool downCommandSent;
  
  // Debounce timers for directions
  unsigned long lastLeftDebounceTime;
  unsigned long lastRightDebounceTime;
  unsigned long lastUpDebounceTime;
  unsigned long lastDownDebounceTime;
};

// Initialize joystick state
JoystickState joystick = {
  512, 512, false, HIGH, 0, false,
  false, false, false, false,
  false, false, false, false,
  false, false, false, false,
  0, 0, 0, 0
};

// Haptic feedback settings
unsigned long hapticStartTime = 0;
unsigned long hapticDuration = 100; // milliseconds

// Haptic pattern settings
#define SHORT_PULSE_DURATION 100   // milliseconds for short pulse (.)
#define LONG_PULSE_DURATION 300    // milliseconds for long pulse (-)
#define PAUSE_BETWEEN_PULSES 150   // milliseconds between pulses in pattern

void setup() {
  // Initialize serial communication
  Serial.begin(9600);
  softSerial.begin(9600);
  
  // Configure joystick select pin as input with pull-up resistor
  pinMode(JOYSTICK_SELECT_PIN, INPUT_PULLUP);
  
  // Configure haptic pin as output
  pinMode(HAPTIC_PIN, OUTPUT);
  digitalWrite(HAPTIC_PIN, LOW);
  
  // Initialize joystick states
  joystick.lastSelectState = digitalRead(JOYSTICK_SELECT_PIN);
  joystick.selectPressed = (joystick.lastSelectState == LOW);
  
  // Read initial joystick position
  joystick.xValue = analogRead(JOYSTICK_X_PIN);
  joystick.yValue = analogRead(JOYSTICK_Y_PIN);
  
  // Initialize direction states based on initial position
  updateJoystickDirections();
  joystick.lastLeftPressed = joystick.leftPressed;
  joystick.lastRightPressed = joystick.rightPressed;
  joystick.lastUpPressed = joystick.upPressed;
  joystick.lastDownPressed = joystick.downPressed;
}

void loop() {
  // Check for incoming UART commands
  checkUARTCommands();
  
  // Process joystick inputs
  processJoystick();
  
  // Handle haptic feedback timing
  handleHapticFeedback();
  
  // Small delay for stability
  delay(10);
}

/**
 * Check for incoming UART commands and process them
 */
void checkUARTCommands() {
  // Check hardware Serial (pins 0/1)
  if (Serial.available()) {
    char command = Serial.read();
    processUARTCommand(command);
  }
  
  // Check SoftwareSerial (pins 4/5)
  if (softSerial.available()) {
    char command = softSerial.read();
    processUARTCommand(command);
  }
}

/**
 * Process UART commands for haptic control
 */
void processUARTCommand(char command) {
  // Handle haptic control commands
  if (command == 'y' || command == 'Y') {
    // Play yes pattern: three quick short pulses (light, positive confirmation)
    playHapticPattern("...");
  } else if (command == 'n' || command == 'N') {
    // Play no pattern: four long pulses (emphatic, negative response)
    playHapticPattern("----");
  } else if (command == 't' || command == 'T') {
    // Play test/signal pattern: long-short-long pulses
    playHapticPattern("-.-");
  } else if (command == 'w' || command == 'W') {
    // Play win pattern: four dots, two dashes (....--)
    playHapticPattern("....--");
  } else if (command == 'l' || command == 'L') {
    // Play lose pattern: four dashes, two dots (----..)
    playHapticPattern("----..");
  }
}

/**
 * Process joystick inputs with debouncing
 */
void processJoystick() {
  // Read current joystick values
  joystick.xValue = analogRead(JOYSTICK_X_PIN);
  joystick.yValue = analogRead(JOYSTICK_Y_PIN);
  
  // Process select button
  processSelectButton();
  
  // Process directional inputs
  processDirectionalInputs();
}

/**
 * Process select button with debouncing
 */
void processSelectButton() {
  // Read current select button state
  int reading = digitalRead(JOYSTICK_SELECT_PIN);
  
  // Check if button state changed (for debouncing)
  if (reading != joystick.lastSelectState) {
    joystick.lastSelectDebounceTime = millis();
    joystick.lastSelectState = reading;  // Update immediately to prevent timer reset
  }
  
  // Apply debounce logic
  if ((millis() - joystick.lastSelectDebounceTime) > DEBOUNCE_DELAY) {
    // Button state has been stable for debounce period
    bool currentPressed = (reading == LOW);
    if (currentPressed != joystick.selectPressed) {
      joystick.selectPressed = currentPressed;
      
      // Button pressed (LOW because of pull-up resistor)
      if (joystick.selectPressed && !joystick.selectPressedFlag) {
        joystick.selectPressedFlag = true;
        
        // Send select command via UART
        sendJoystickCommand('s');
      } else if (!joystick.selectPressed) {
        joystick.selectPressedFlag = false;
      }
    }
  }
}
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

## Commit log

2025-10-03 Initial main board code made with cursor
2025-10-10 Adding final schematic models
    [COM-09032.step, coarse.kicad_sch, final_schematics.kicad_pcb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]
2025-10-17 Test code on main board
    [coarse.kicad_sch, final_schematics.kicad_sch, main_board.kicad_sch]
2025-10-27 Getting ready for testing in sim with main board
2025-10-27 Almost ready to play a full game
    [coarse.kicad_sch, main_board.kicad_sch]
2025-11-04 Fix servos getting stuck in the wrong posision
    [main-board.ino]
2025-11-04 Main board code basically done'
2025-11-04 Fix weird haptics bugs
    [coarse.ino, fine.ino]
2025-11-05 Add full game board condition
2025-11-13 change indicies to the real board
2025-11-14 Add queue fixes so it can't get stuck in weird modes
    [main-board.ino]
2025-12-02 Add flowcharts
    [coarse.kicad_sch, fine_motor_control.kicad_sch, main_board.kicad_sch]
